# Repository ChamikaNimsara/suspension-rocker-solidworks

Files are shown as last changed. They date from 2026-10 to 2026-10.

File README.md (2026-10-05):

# Suspension Rocker Design, Kinematics and FEA in SolidWorks

**Author:** Chamika Nimsara | **Software:** SolidWorks 2023 | **Completed:** 5 October 2026

A conceptual front-corner pushrod suspension rocker project covering parametric modelling, a serviceable pivot assembly, travel verification, linear static FEA, mesh refinement and a mass-reduction iteration.

The optimized 6061-T6 rocker removes **41.23 g (6.72%)** using a through-hole while retaining the same pickup geometry. The matched-mesh bump comparison shows **1.66% higher peak nodal stress and 31.74% higher maximum displacement**. This is a documented mass/stiffness trade-off, rather than a claim that every performance metric improved.

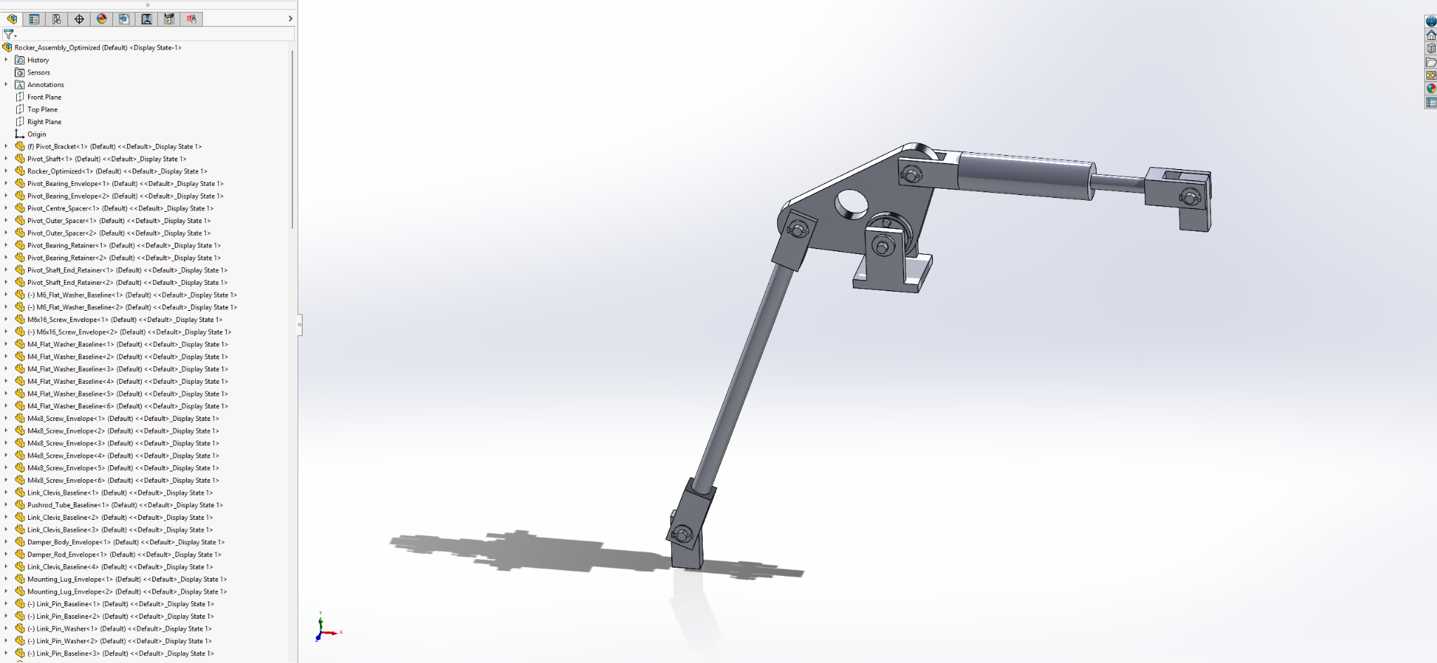
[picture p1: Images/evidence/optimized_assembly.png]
Optimized rocker assembly


## Results at a glance

| Quantity | Baseline | Optimized |
|---|---:|---:|
| Rocker body mass | 613.86 g | 572.63 g |
| Bump +30 mm / 6 kN, nodal stress, matched mesh | 82.43 MPa | 83.80 MPa |
| Bump +30 mm / 6 kN, resultant displacement, matched mesh | 0.04651 mm | 0.06127 mm |
| Bump fine-mesh nodal stress | 85.14 MPa | 83.87 MPa |
| Bump fine-mesh resultant displacement | 0.04655 mm | 0.06128 mm |
| Reverse 2 kN nodal stress | 31.60 MPa | 31.30 MPa |
| Reverse 2 kN resultant displacement | 0.01734 mm | 0.02256 mm |

Matched mesh = maximum/minimum mesh size **1.5/0.3 mm**; fine mesh = **1.2/0.24 mm**. Stress is a maximum nodal von Mises result, and displacement is maximum URES, not a measured relative pickup displacement.

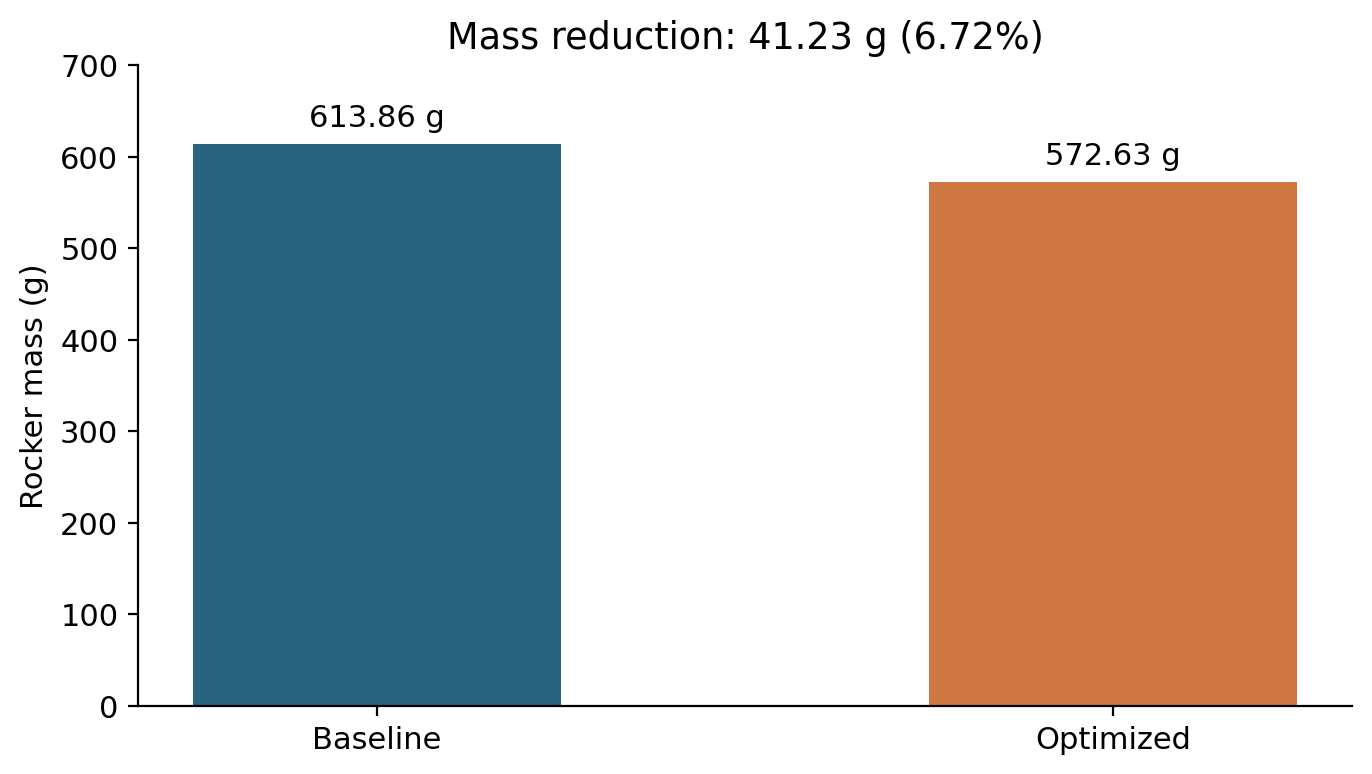
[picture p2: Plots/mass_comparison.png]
Mass comparison

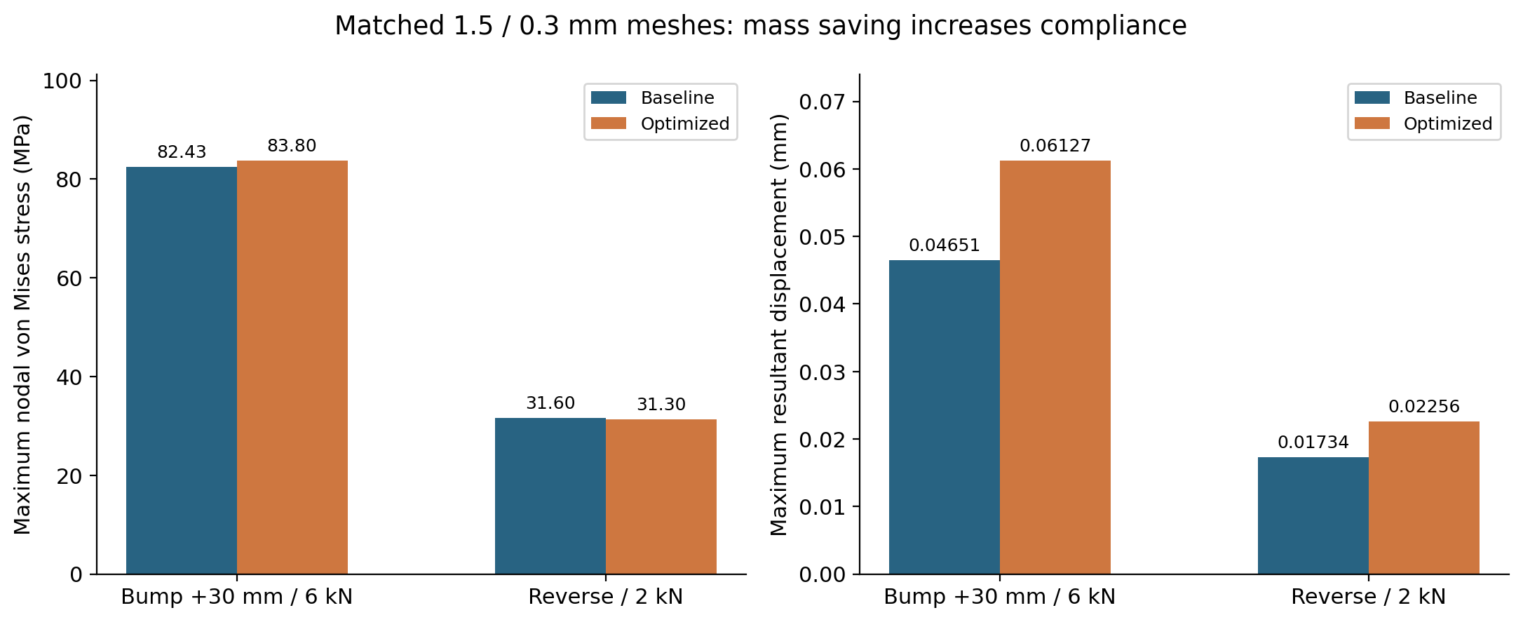
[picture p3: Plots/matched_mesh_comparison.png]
Matched-mesh structural comparison


## What was built and checked

- Baseline and optimized rocker bodies with unchanged A/O/B pickup locations.
- Pivot shaft, simplified bearings, spacers, retainers, fasteners and double-shear linkage joints.
- Pushrod and telescoping damper envelopes connected to a fixed mount and guided input.
- Nominal ride motion ratio approximately **0.80**, with travel-dependent variation measured from CAD.
- **30 mm bump / 30 mm droop** mechanism sweep; 21.19 mm compression and 27.33 mm extension from ride.
- Baseline ride, bump, droop and reverse bearing-load studies; optimized bump and reverse studies.
- Baseline and optimized bump mesh-refinement comparisons and reaction-force checks.
- Smooth optimized assembly motion reported by the author; no remaining interferences at the three checked positions after eight known thread-envelope overlaps were ignored.
- Optimized rocker and assembly drawings, including BOM and balloons, exported to PDF.

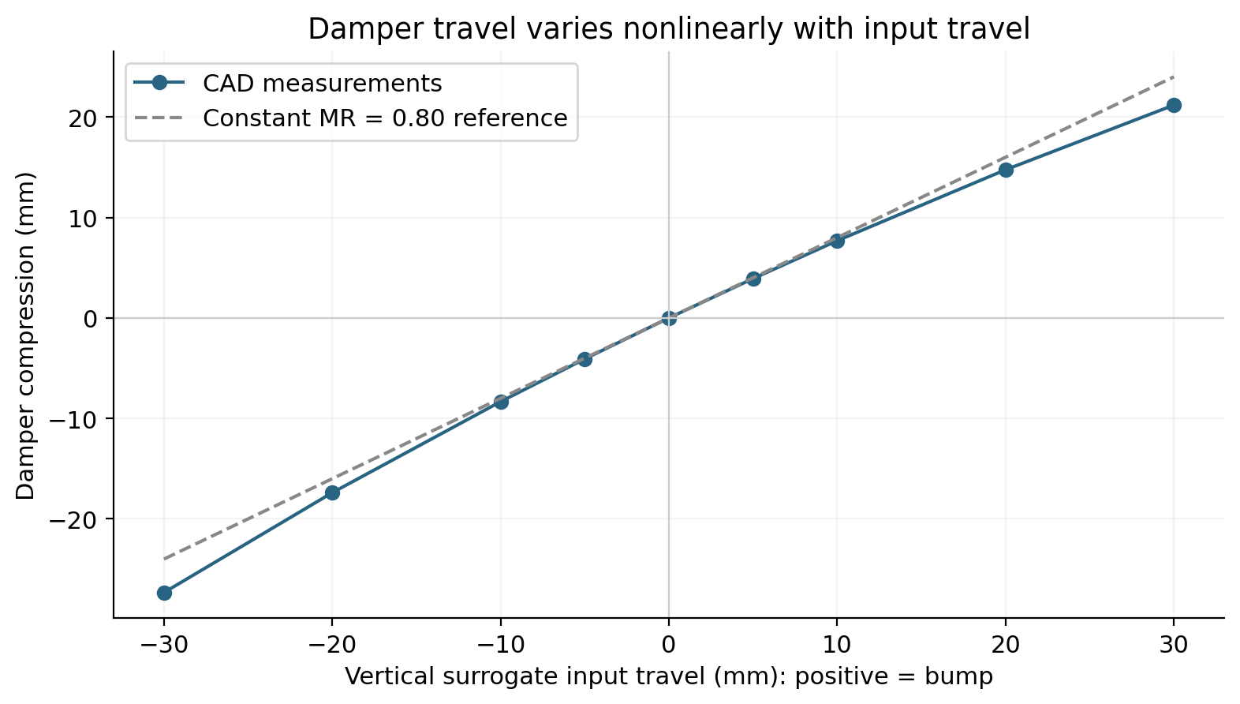
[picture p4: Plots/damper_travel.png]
Damper travel

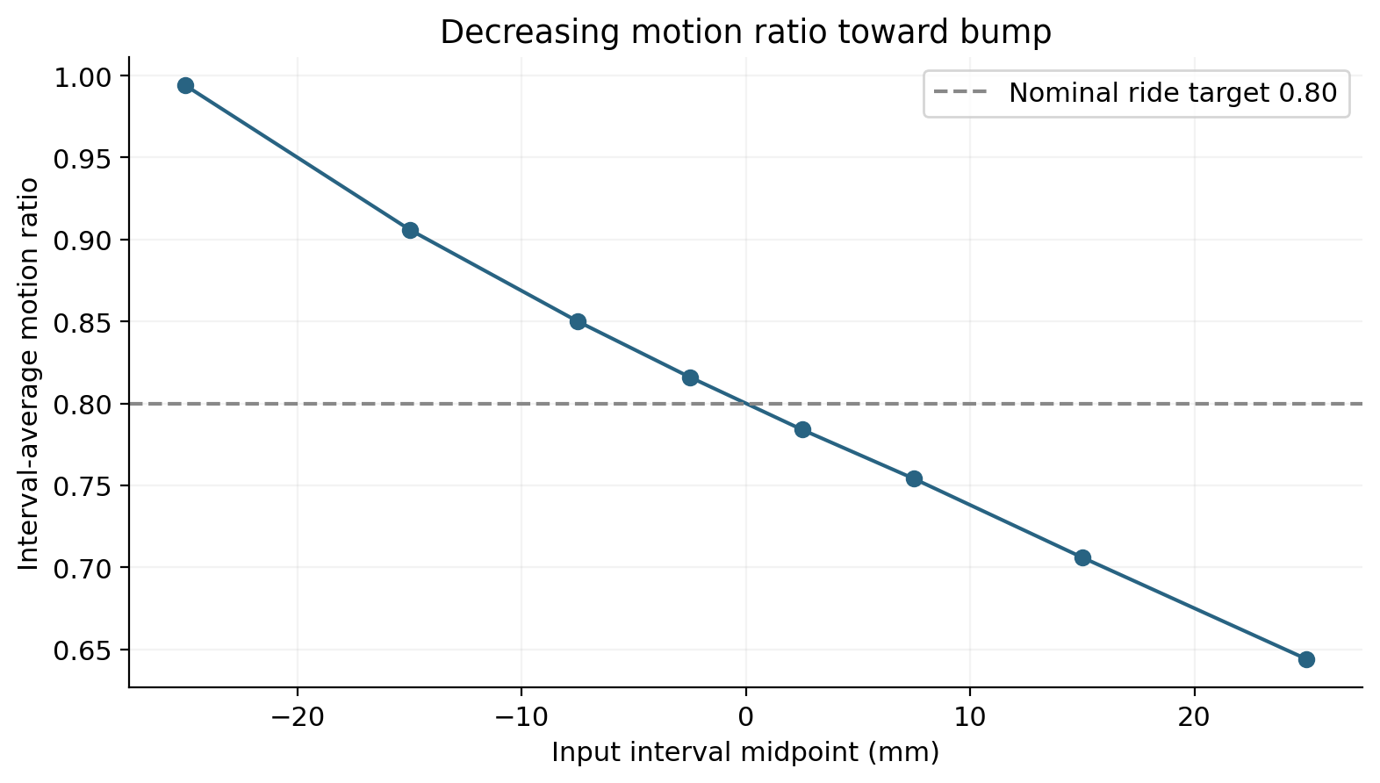
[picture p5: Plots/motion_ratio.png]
Motion ratio


## Read the engineering work

1. [Design basis and final geometry](docs/01_design_basis.md)
2. [Mechanism physics and kinematics](docs/02_kinematics.md)
3. [Loads, FEA setup and mesh checks](docs/03_structural_analysis.md)
4. [Optimization and interpretation](docs/04_optimization.md)
5. [Assembly verification and drawing status](docs/05_verification.md)
6. [Evidence gallery and data provenance](docs/06_evidence.md)
7. [Native files and publishing the repository](docs/07_repository_guide.md)
8. [Engineering Brief](docs/engineering_brief.md)

## Drawings

- [Optimized rocker part drawing](Drawings/Rocker_Optimized.pdf)
- [Optimized assembly drawing and BOM](Drawings/Rocker_Assembly_Optimized.pdf)

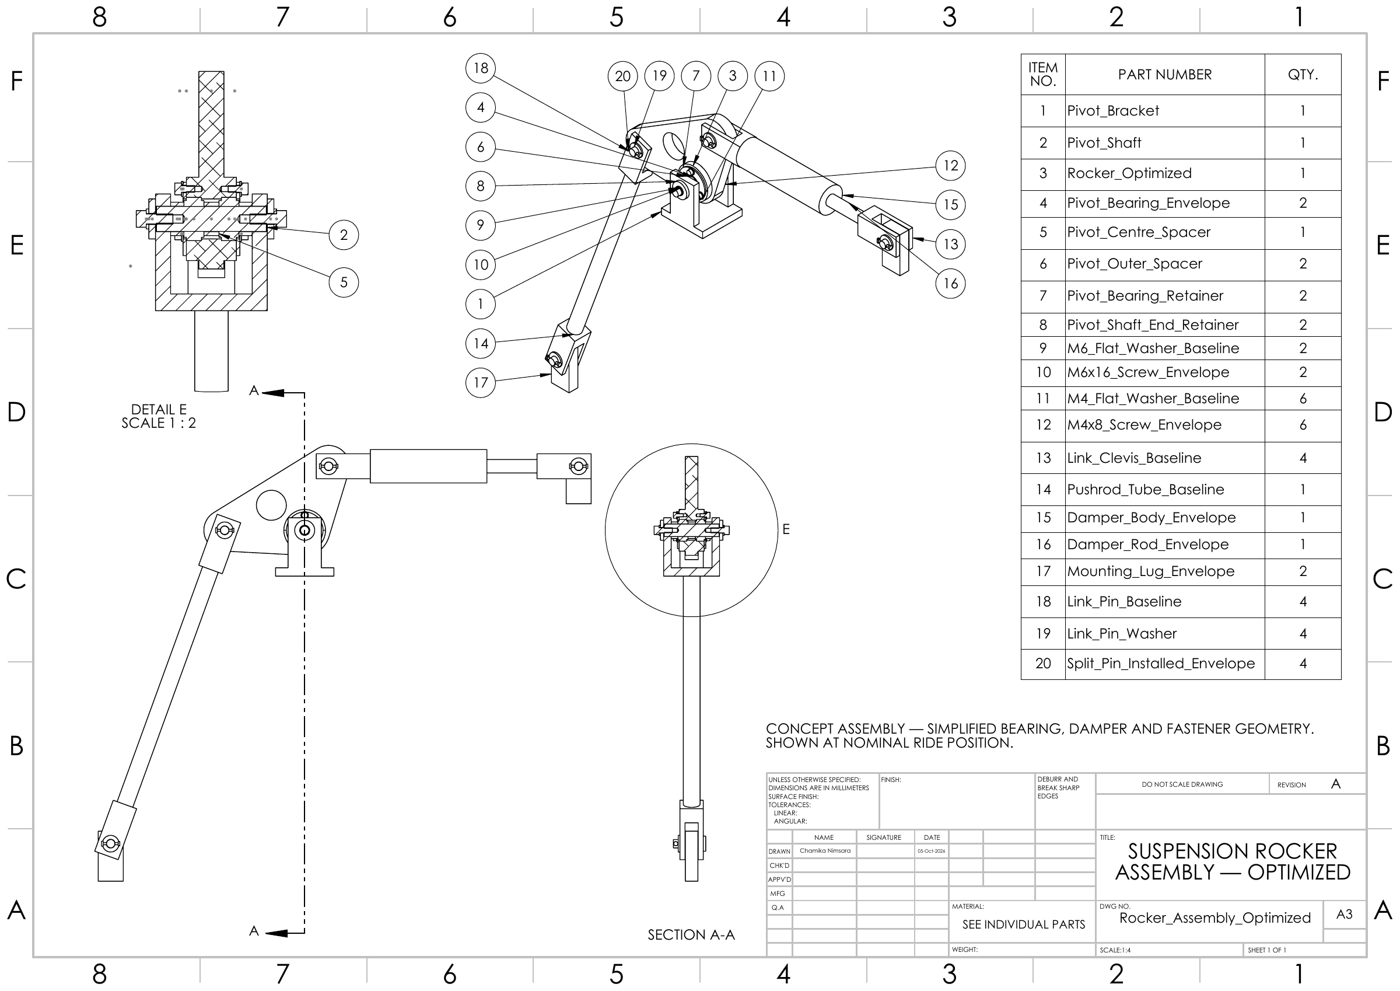
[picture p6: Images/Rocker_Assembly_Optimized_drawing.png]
Assembly drawing preview


## Repository contents

| Folder | Contents |
|---|---|
| `docs/` | Engineering explanations, final assumptions, methods and limitations |
| `Images/` | Drawing previews and selected original project screenshots |
| `Plots/` | Six reproducible figures, each in PNG and SVG |
| `Results/` | CSV records for kinematics, loads, mass, FEA, convergence, BOM and assembly checks; two interference-calculation spreadsheets and the screenshot evidence manifest |
| `Drawings/` | Two exported PDF drawings and their native `.SLDDRW` sources |
| `scripts/` | Python chart generation from the CSV records |
| `CAD/` | 22 native `.SLDPRT` models and two `.SLDASM` assemblies |
| `Simulation/` | Locally copied `.CWR` solver results, `.MFC`/`.SL4` artifacts and logs; `.CWR` and `.LOG` files are ignored by Git |
| `Animations/` | Baseline mechanism travel video, `Rocker_Travel_Baseline.avi` |

## Reproduce the figures

```bash
python -m pip install -r requirements.txt
python scripts/generate_charts.py
```

This recreates the plots from recorded values. It does **not** rerun SolidWorks or reconstruct a solver model. Native CAD, drawing sources, solver artifacts and the baseline animation are present in the local repository folders. The copied assemblies' and drawings' references and the studies' result paths have not been verified as part of this documentation review; see [the repository guide](docs/07_repository_guide.md). Git-ignored solver files are local artifacts and are not included by a normal Git commit.

## Interpretation and scope

The moving lower mount C is a **vertical surrogate input**, not a complete upright/wishbone model. Motion ratio is therefore damper compression per unit guided input travel. The full vehicle's wheel motion ratio would require its actual suspension geometry.

The mechanism has a decreasing motion ratio toward bump; it does not meet a constant 0.80 ±5% target across the whole sweep. Only selected static rocker load cases were analyzed. Bearing life, joint/shaft/bracket strength, chassis attachment, fatigue, impact loads and physical proof testing are outside the completed scope.

Drawings communicate nominal concept geometry; fits, general tolerances and a manufacturing release are not established. The eight ignored overlaps are known simplified screw/thread intersections, not a blanket permission to ignore interference. Grey reference markers in the assembly detail were intentionally retained by the author.

No open-source license has been selected. Choose an appropriate license before inviting reuse of the design or code.

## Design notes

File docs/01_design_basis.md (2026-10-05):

# Design basis and geometry

## Final scope

This portfolio project models one conceptual front-corner rocker mechanism. A rocker is a bell crank: it turns a force and displacement along the pushrod into a force and displacement along the spring/damper axis. The pivot transmits the remaining force to the chassis support.

The CAD project is complete within its stated concept scope. It is not a production suspension or a validated vehicle-specific design. The final material is **6061-T6**, not the 7075-T6 proposed in the early brief.

## Final inputs and assumptions

| Parameter | Adopted value | Interpretation |
|---|---:|---|
| Reference front stiffness | 67,500 N/m | Treated as a wheel-rate reference for the local spring calculation |
| Nominal ride motion ratio | 0.80 | Compression / guided vertical input travel |
| Derived local spring rate | 105.47 N/mm | 67.5 / 0.8²; nominal equivalent, not a purchased spring |
| Mechanism input range | -30 to +30 mm | Negative droop, positive bump |
| Static proof sensitivity input | 6,000 N | Assumed vertical input load, not a measured race load |
| Reverse input | -2,000 N | Assumed load reversal at ride |
| Material E / Poisson ratio | 69,000 MPa / 0.33 | SolidWorks analysis material settings |
| Density | 2,700 kg/m³ | Analysis/CAD material setting |
| Yield / tensile strength | 275 / 310 MPa | Library values, not a billet certificate |

Vehicle mass and track inspired the concept, but do not independently derive the applied 6 kN load. Real sizing would require actual hard points, aero loads, tyre forces, load histories and an operating duty cycle.

## Coordinate convention

O is the rocker pivot, x points right in the layout, y points up and z follows the shaft. All coordinates below are in millimetres and refer to the planar ride layout.

| Point | x | y | Function |
|---|---:|---:|---|
| O | 0 | 0 | Fixed pivot |
| A | -96 | 0 | Pushrod pickup |
| B | 28.73604009 | 76.8 | Damper pickup |
| C | approximately -232.81 | approximately -375.88 | Guided lower pushrod mount |
| D | approximately 328.74 | 76.8 | Fixed damper mount |

OA = 96 mm, OB = 82 mm; pushrod pin-centre length AC = 400 mm and nominal damper pin-centre length BD ≈300 mm. Rounded C/D coordinates are sufficient for interpretation; the saved CAD constraints govern the model.

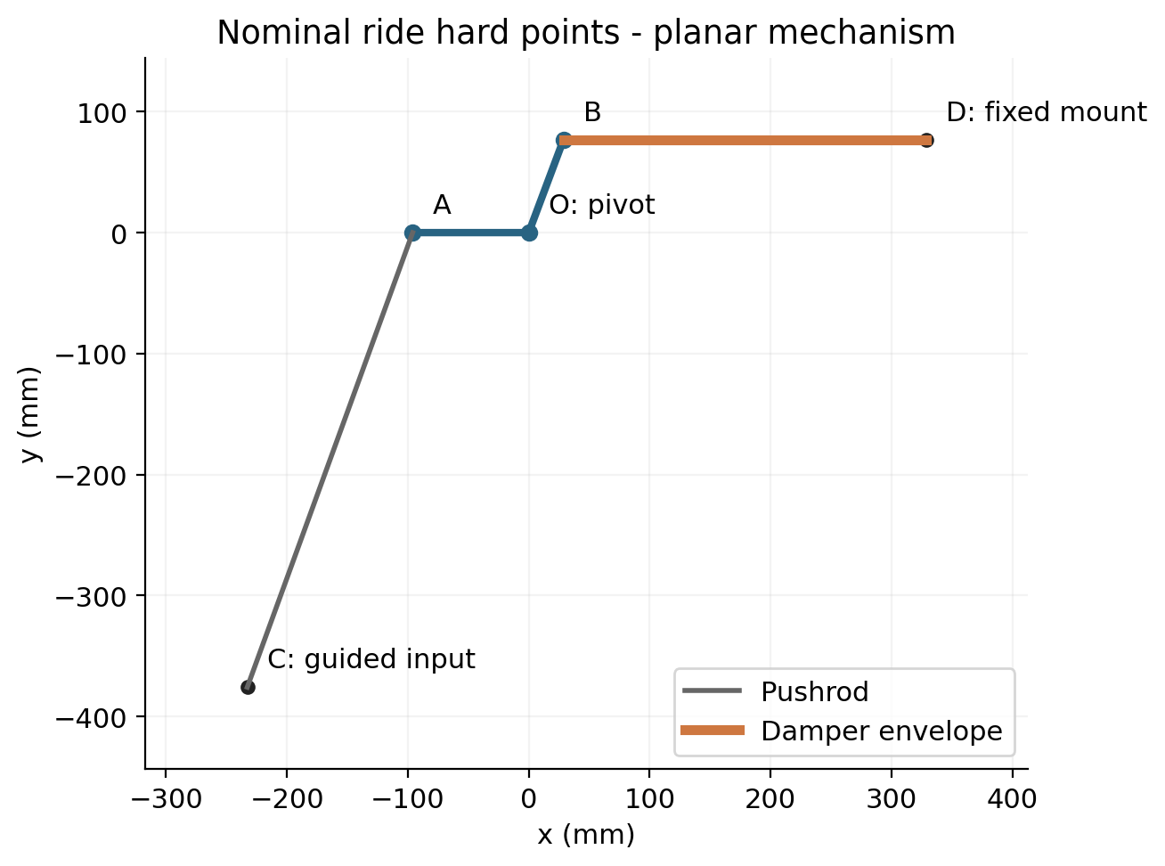
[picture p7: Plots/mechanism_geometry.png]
Ride geometry


## Rocker body features

| Feature | Final nominal geometry |
|---|---|
| Plate | 15 mm, mid-plane extrusion |
| Pivot hub | Ø50 mm, 30 mm total axial thickness |
| Pivot through opening | Ø24 mm |
| Bearing seat | Ø26 mm, 9 mm depth on each end |
| Linkage holes | Ø10 mm through |
| Outer profile | Tangent lines linking R25 pickup arcs and R30 pivot profile |
| Retainer pattern | 3 × M4 ×0.7 each side, Ø36 mm PCD, 120° spacing |
| Thread / tap drill depth | 6 / 9 mm each side; Ø3.3 mm drill |
| Optimized window | Ø36 mm through, centre (-40,+30) relative to O |
| Window-to-hub radial clearance | 7 mm nominal: 50 - 25 - 18 |

No fillets were added to the final nominal model. Hole position, root geometry and window placement influence the load path; nominal clearances do not establish manufacturing tolerances or fatigue durability.

## Changes from the early concept

| Early proposal | Completed project |
|---|---|
| 7075-T6 body | 6061-T6 body |
| 50 mm bump / 30 mm droop | Demonstrated ±30 mm guided-input travel |
| Preliminary 95 mm pushrod radius | Final OA = 96 mm |
| Hypothetical 50 N/mm spring example | 105.47 N/mm local spring-rate calculation |
| Constant MR within ±5% as an initial aim | Measured decreasing ratio; departure explicitly documented |
| 0.20-0.30 kg preliminary mass ambition | Baseline 0.61386 kg; optimized 0.57263 kg |
| Proposed blend radii, certified material and release fits | Nominal concept CAD and drawings; those release items remain open |

The early concept brief is not used as final numerical evidence. This document describes what was actually modelled and measured.

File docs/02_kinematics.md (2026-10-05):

# Mechanism physics and kinematics

## Displacement and force transformation

For a small rotation dθ, the velocity of a rocker pickup is perpendicular to the arm from O. Its projection along the connected link axis determines the axial motion transferred through that link. The rigid pushrod retains its length, so the velocities of A and C have equal projections along AC; damper compression depends on the relative axial velocity of B and D. The effective arm is therefore

$$e=|\mathbf r\times\hat{\mathbf u}|.$$

The arm's physical radius alone is not the motion ratio: pushrod angle and damper line of action also matter. At ride, A has a 96 mm horizontal arm, while a horizontal damper force at B has a 76.8 mm moment arm. Their ratio is 0.80 for the guided-input layout near ride.

Define positive q as upward guided input C and positive s as damper compression:

$$MR=\frac{ds}{dq}.$$

Under lossless, quasi-static virtual work,

$$F_q\,dq=F_d\,ds,\qquad F_d=F_q/MR.$$

A damper that moves less than the input must carry more force. At ride MR ≈0.80, a 6 kN input corresponds to approximately 7.5 kN at the damper. A bearing pressure is applied at the rocker pickup to represent this force transfer in the structural model.

## Spring-rate relationship

For an approximately constant local MR, the equivalent input stiffness is

$$k_q\approx k_sMR^2.$$

One factor of MR comes from displacement transformation and the other from force transformation. A 67.5 N/mm input stiffness at MR=0.80 requires approximately 105.47 N/mm spring stiffness. This is a local calculation, not a specification of a catalogue spring.

When MR varies and the spring carries force, the tangent stiffness includes a geometric term:

$$\frac{dF_q}{dq}=k_sMR^2+F_s\frac{dMR}{dq}.$$

Preload and ride force matter to that term. It is not valid to claim a constant wheel rate across travel solely from the ride ratio.

## Recorded sweep

| Input q (mm) | Mate distance (mm) | Damper length BD (mm) | Compression s (mm) |
|---:|---:|---:|---:|
| -30 | 405.88 | 327.34 | -27.33 |
| -20 | 395.88 | 317.40 | -17.39 |
| -10 | 385.88 | 308.34 | -8.33 |
| -5 | 380.88 | 304.09 | -4.08 |
| 0 | 375.88 | 300.01 | 0.00 |
| +5 | 370.88 | 296.09 | 3.92 |
| +10 | 365.88 | 292.32 | 7.69 |
| +20 | 355.88 | 285.26 | 14.75 |
| +30 | 345.88 | 278.82 | 21.19 |

The independently displayed lengths and compression records are rounded to 0.01 mm; small differences in their subtraction should not be treated as new measurements.

Travel curve

The central ±5 mm estimate is (3.92 - (-4.08))/10 = **0.800**. Finite-interval ratios decrease toward bump: 0 to +10 mm gives 0.769, +10 to +20 gives 0.706, and +20 to +30 gives 0.644. Toward droop, interval values are 0.833, 0.906 and 0.994. The smaller ±5 mm intervals are retained in the CSV and plot.

Interval-average motion ratio

The plot uses Δs/Δq at interval midpoints; it is not an exact analytic derivative. Measured travel is **21.19 mm compression**, **27.33 mm extension** and **48.52 mm total excursion**. The envelope model does not establish a real damper's available stroke or bump-stop margin.

## Important boundary of the result

C is constrained to a vertical guide. There is no upright, wishbone geometry, steering sweep or tyre contact point in this assembly. Call this ratio damper-to-guided-input MR; mapping it to actual wheel motion requires a full suspension model. The decreasing ratio also departs from the initial constant-ratio ±5% ambition and is retained as a measured result, not hidden as an acceptance pass.

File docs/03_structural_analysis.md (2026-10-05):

# Loads, structural analysis and mesh checks

## What the analysis represents

Linear elastic static studies were performed on the rocker solid in SolidWorks Simulation. Force inputs are selected concept load cases, not measured wheel loads or dynamic test results. The bearing-load models are the final reported structural studies; preliminary uniform cylindrical traction studies are not mixed into the headline comparison.

A real joint transfers force through contact pressure around a pin. A point force would concentrate the load unrealistically. Distributed bearing loads provide a more representative load direction, although they still do not resolve actual pin flexibility, clearance or nonlinear contact.

## Material and fixtures

- 6061-T6, isotropic linear elasticity: E = 69,000 MPa, ν =0.33, density =2,700 kg/m³.
- Material-library yield/tensile values 275/310 MPa, without certified billet data.
- Fixed Hinge on the two Ø26 mm bearing seats: radial and axial displacement constrained, circumferential freedom retained.
- A small angular-reference fixture at a split-line vertex, approximately (13,0,15) mm, removes the otherwise free rigid rotation about the pivot.
- The angular reference is a numerical stabilizer. Its reaction is checked; it is not a physical chassis attachment.
- Soft springs, inertia relief and large displacement were off; free-body reaction extraction was on.

## Force magnitudes and directions

| Case | Vertical input | Pushrod magnitude | Damper magnitude | Pushrod axis angle, body-fixed | Damper axis angle, body-fixed |
|---|---:|---:|---:|---:|---:|
| Ride proof | +6,000 N | 6,385.07 N | 7,500 N | 70° | 0° |
| +30 mm bump proof | +6,000 N | 6,412.26 N | 9,807.04 N | 86.55° | 19.66° |
| -30 mm droop proof | +6,000 N | 6,420.13 N | 5,728.17 N | 49.65° | -20.42° |
| Ride reverse | -2,000 N | 2,128.36 N | 2,500 N | 70° | 0° |

Angles are link-axis orientations measured from the rocker's body-fixed x axis in the rocker-only FEA model. This frame coincides with the assembly's global frame at ride, but rotates with the rocker during bump and droop. If θ is the rocker rotation from ride, the assembly-global link angle equals the listed body-fixed angle plus θ. For example, at +30 mm bump θ is approximately -17.21°, giving global pushrod/damper angles of approximately 69.34°/2.45°. The vertical input in the table is defined along the assembly's global guided-input axis, not the body-fixed y axis. In proof cases the pushrod force follows the axis from C toward A and the damper force opposes the axis from B toward D; reverse changes both directions. Exact CAD coordinates govern the case. Loads were recalculated at the displaced geometry, rather than applying the ride force unchanged throughout travel.

Moment equilibrium about O requires $F_pe_p=F_de_d$. Ride proof torque magnitude is about 576 N·m. Bump proof torque magnitude is about 614.46 N·m; droop proof approximately 469.71 N·m. Reverse ride torque magnitude is about 192 N·m.

## Reported maximum results

| Design / case | Mesh max/min (mm) | Nodal von Mises (MPa) | URES (mm) | Equivalent strain |
|---|---|---:|---:|---:|
| Baseline ride proof | 1.5/0.3 | 71.70 | 0.04787 | 0.0007846 |
| Baseline reverse | 1.5/0.3 | 31.60 | 0.01734 | 0.0003425 |
| Baseline bump proof | 1.5/0.3 | 82.43 | 0.04651 | 0.0009858 |
| Baseline bump proof, fine | 1.2/0.24 | 85.14 | 0.04655 | 0.001002 |
| Baseline droop proof | 1.5/0.3 | 65.60 | 0.04061 | 0.0007201 |
| Optimized bump proof | 1.5/0.3 | 83.80 | 0.06127 | 0.001001 |
| Optimized bump proof, fine | 1.2/0.24 | 83.87 | 0.06128 | 0.001004 |
| Optimized reverse | 1.5/0.3 | 31.30 | 0.02256 | 0.0003441 |

URES is maximum absolute resultant displacement. It does not establish relative A-to-B deflection, bearing-seat ovalization or complete suspension compliance. Colour plots use automatic contour scales; compare numeric values, not colour intensity. Displayed deformation is magnified by the plot scale, not actual movement.

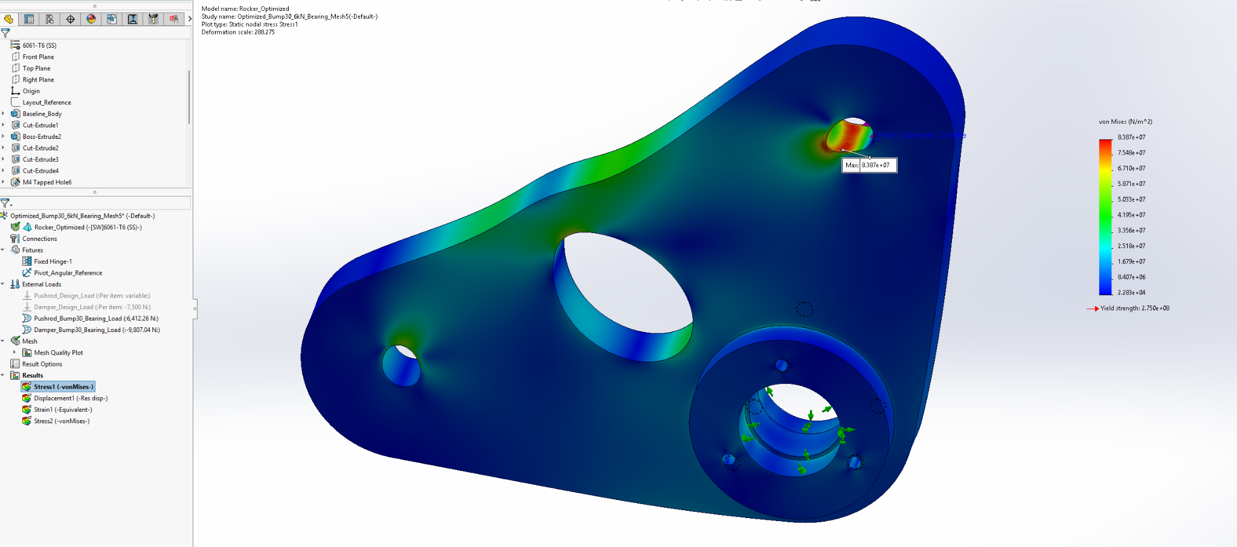
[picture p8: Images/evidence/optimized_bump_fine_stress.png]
Optimized bump fine stress

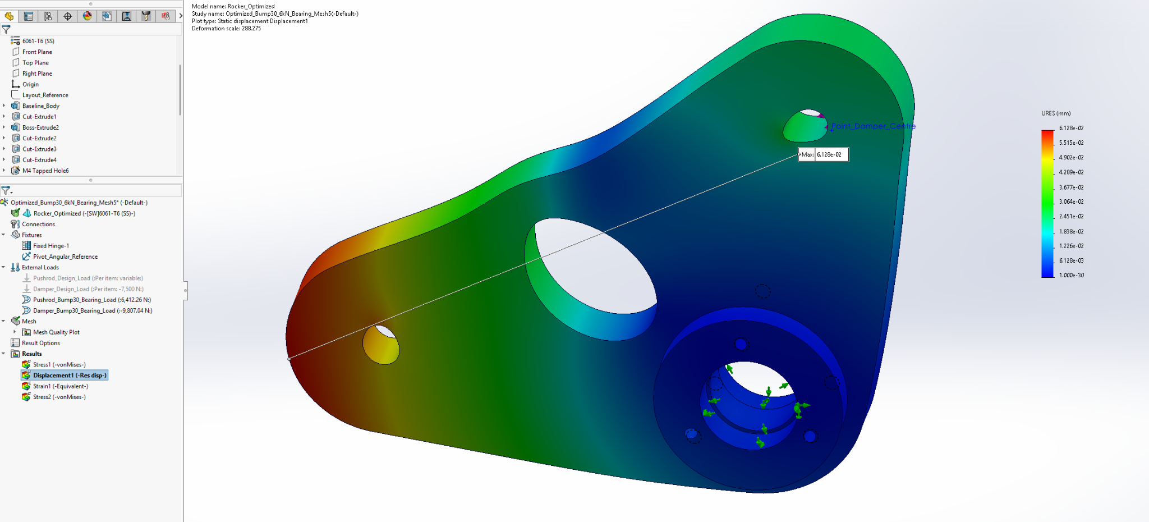
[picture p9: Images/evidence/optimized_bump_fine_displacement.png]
Optimized bump fine displacement


## Mesh and convergence

High-quality solid blended curvature-based meshing was used, with Jacobian checks at 16 points, 16 elements around a circle and growth ratio 1.4. The final refinement interval is summarized below.

| Design | Coarse nodes / elements | Fine nodes / elements | Stress change | URES change | Strain change |
|---|---|---|---:|---:|---:|
| Baseline bump | 784,424 / 554,512 | 1,342,608 / 956,878 | +3.29% | +0.086% | +1.64% |
| Optimized bump | 748,824 / 527,910 | 1,267,794 / 901,045 | +0.084% | +0.016% | +0.300% |

The adopted project check was less than 5% change in stress and 2% in displacement over the final refinement. Both pass that numerical check. Baseline fine maximum aspect ratio was 5.1419, optimized fine 5.2676, with no reported distorted elements or aspect ratios above 10. This documents stability across the final interval; it does not prove exact stress convergence, eliminate singularities or validate the fixture model.

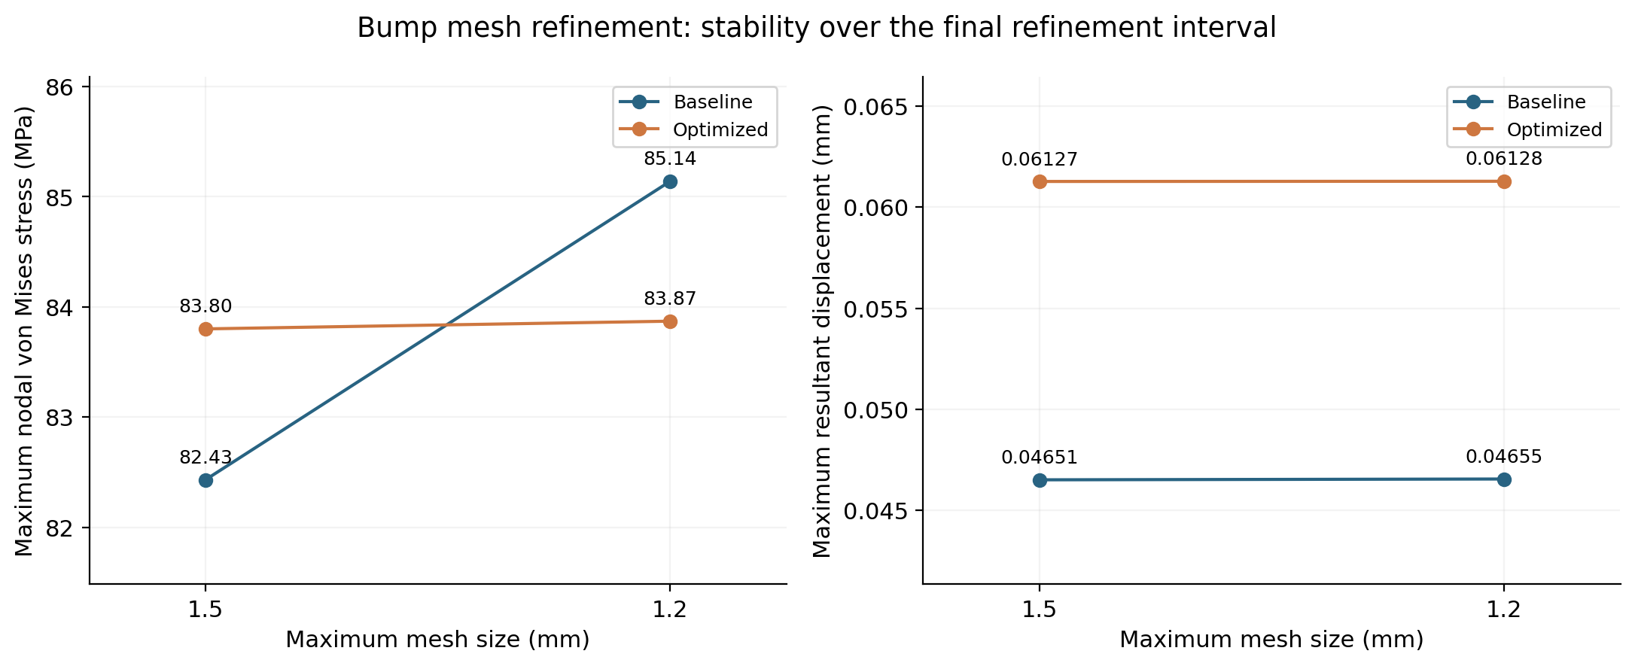
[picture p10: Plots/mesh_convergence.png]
Mesh refinement results


## Equilibrium and stabilization checks

For the optimized fine bump case, the expected net pivot reaction in the same body-fixed FEA frame is approximately (8849.47,-3101.18,0) N. The extracted result in that frame was (8849.6,-3101.3,+0.0698) N. These components are not expressed in the assembly's global frame at bump. The angular-reference resultant was approximately **0.411 N**, with pivot-axis moment approximately **0.00276 N·m**, small compared with the applied 614.46 N·m torque magnitude. This supports that the stabilizer was not carrying a material fraction of the intended load.

The optimized reverse angular-reference resultant was approximately 0.310 N with pivot-axis moment -0.00281 N·m. The baseline fine bump reference resultant was approximately 0.265 N with pivot-axis moment 0.000501 N·m. Reaction agreement is a model consistency check, not proof of physical correctness.

## Limits

No optimized ride/droop study or reverse mesh-refinement sequence is claimed. Bump was the largest-stress baseline case tested and was selected for the optimized refinement. All assembly hardware remains outside the rocker-only stress assessment. No fatigue spectrum, modal analysis, buckling study, impact simulation, nonlinear contact study or physical testing is included. A yield-strength/peak-stress quotient alone would not establish a safe vehicle design.

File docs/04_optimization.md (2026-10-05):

# Mass reduction and interpretation

The optimization was a single geometric iteration: a Ø36 mm through-window was added at x=-40 mm, y=+30 mm relative to O. Pickup locations, hub and plate thickness were retained so the assemblies use the same mechanism geometry.

Removing material reduces mass, but also reduces the area and bending stiffness through which loads flow. The correct comparison therefore includes mass, stress and displacement under matching boundary conditions.

## Quantified trade-off

| Metric | Baseline | Optimized | Change |
|---|---:|---:|---:|
| Mass | 613.86 g | 572.63 g | -41.23 g / -6.72% |
| Volume | 227,354.57 mm³ | 212,086.43 mm³ | -15,268.14 mm³ |
| Bump stress, 1.5/0.3 mm mesh | 82.43 MPa | 83.80 MPa | +1.66% |
| Bump URES, 1.5/0.3 mm mesh | 0.04651 mm | 0.06127 mm | +31.74% |
| Reverse stress, 1.5/0.3 mm mesh | 31.60 MPa | 31.30 MPa | -0.95% |
| Reverse URES, 1.5/0.3 mm mesh | 0.01734 mm | 0.02256 mm | +30.10% |

Mass
Matched mesh comparison

At the fine meshes, bump stress is 85.14 MPa baseline and 83.87 MPa optimized, while URES is 0.04655 versus 0.06128 mm. The slight stress decrease in that comparison should not be presented as a robust improvement in strength: coarse-to-fine baseline variation is larger than the between-design difference, and peak nodal stress depends on discretization and local load distribution.

The most defensible conclusion is **6.72% lower rocker body mass, similar computed bump stress, and roughly 32% greater maximum bump displacement** under these idealized cases. Whether that extra compliance is acceptable needs a relative pickup-deflection requirement and a full suspension compliance budget.

## Engineering judgment

The iteration demonstrates the workflow from baseline geometry to a tested mass change. It is not topology optimization or proof that this is the best possible geometry. A second iteration could investigate window shape, blended transitions, fillets and hub proportions, but would need to preserve machinability and reconsider fatigue/contact behaviour. Such changes were not performed in this project.

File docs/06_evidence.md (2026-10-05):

# Evidence gallery and provenance

The numeric CSV records were transcribed from the completed project conversation and supplied SolidWorks screenshots. They are rounded reported results, not raw solver exports. The plot-generation script performs calculations and visualization only.

Selected original screenshots below are retained without alteration; their source names and SHA-256 hashes are in [the evidence manifest](../Results/evidence_manifest.json). Fine-mesh stress and displacement values were visually checked against the included plots during packaging. Other numerical records derive from the recorded project results.

## Optimized assembly at nominal ride position

Optimized assembly at nominal ride position

## Optimized rocker geometry and feature tree

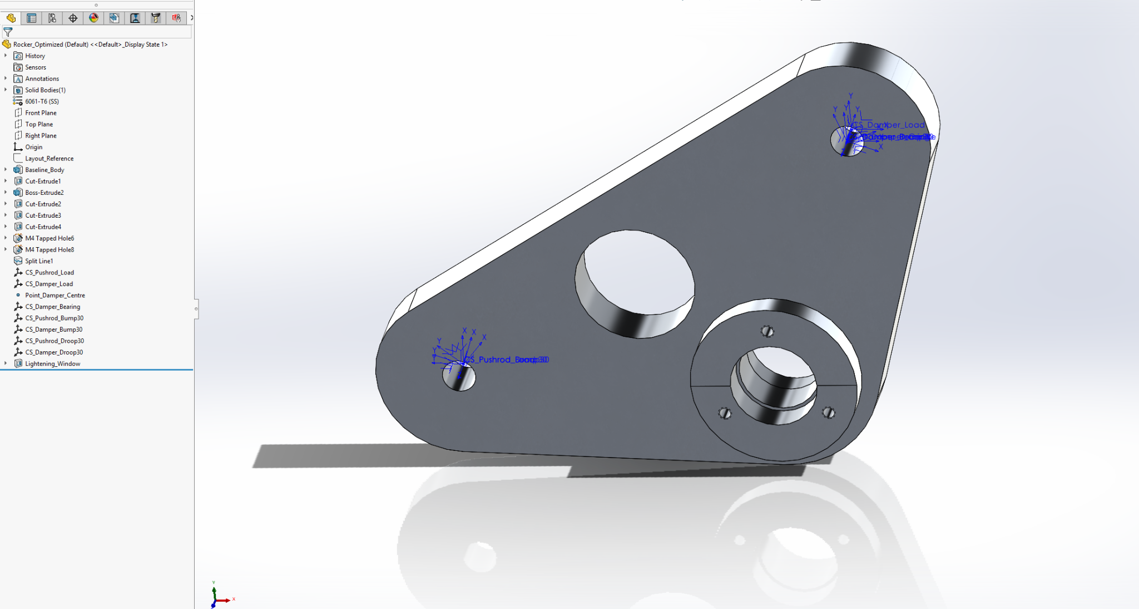
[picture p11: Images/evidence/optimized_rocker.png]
Optimized rocker geometry and feature tree


## Baseline bump, fine mesh: nodal von Mises 85.14 MPa

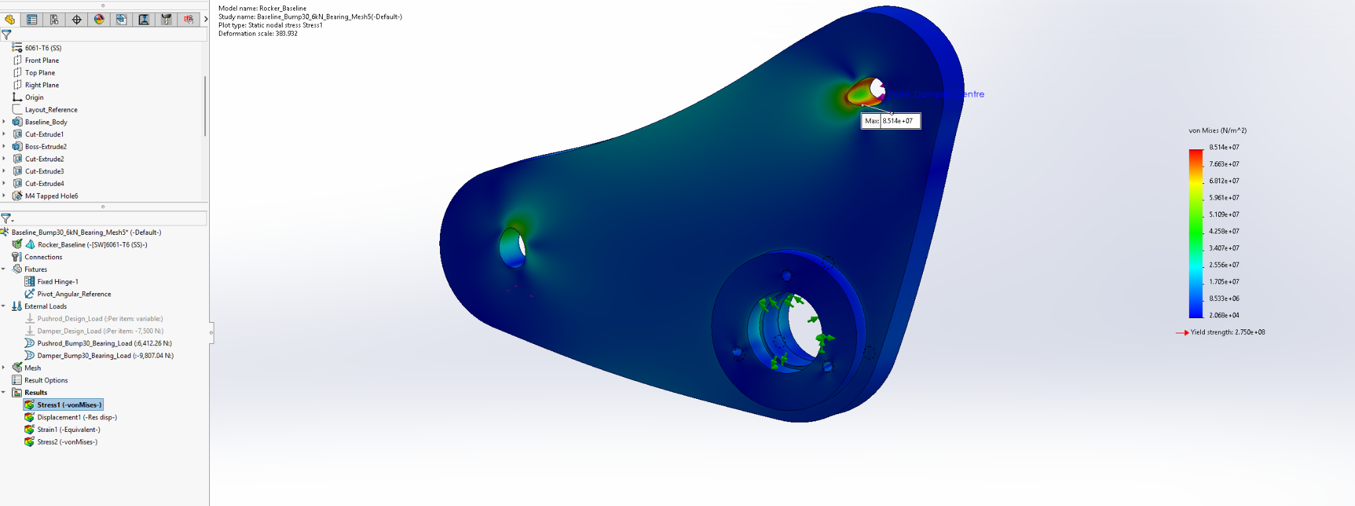
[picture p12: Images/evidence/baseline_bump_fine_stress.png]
Baseline bump, fine mesh: nodal von Mises 85.14 MPa


## Baseline bump, fine mesh: URES 0.04655 mm

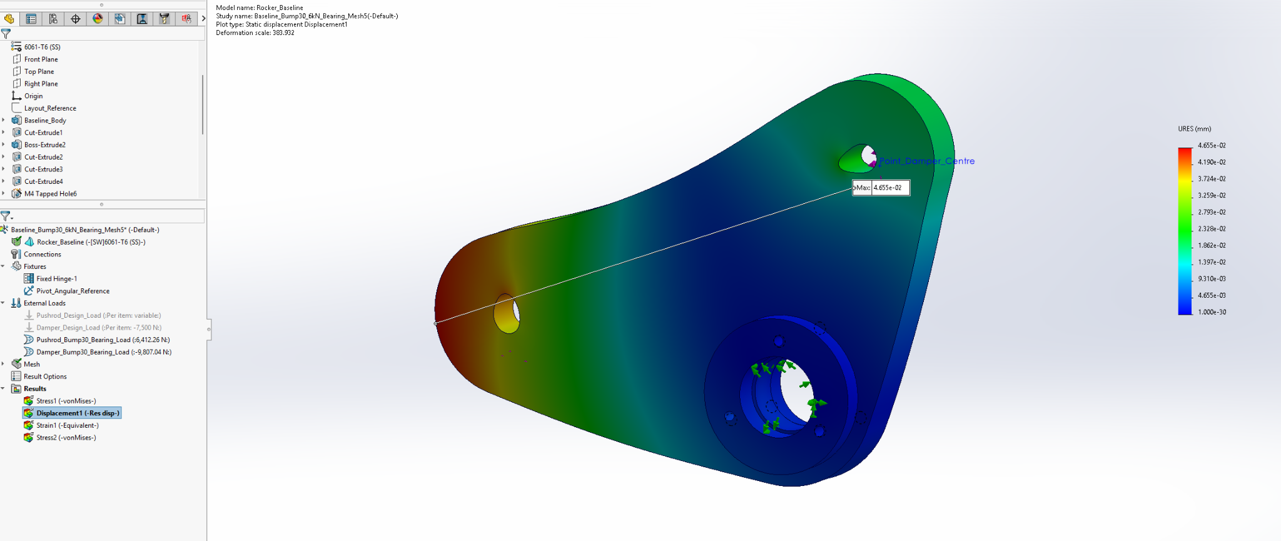
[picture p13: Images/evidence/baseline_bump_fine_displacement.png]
Baseline bump, fine mesh: URES 0.04655 mm


## Baseline bump, fine mesh: ESTRN 0.001002

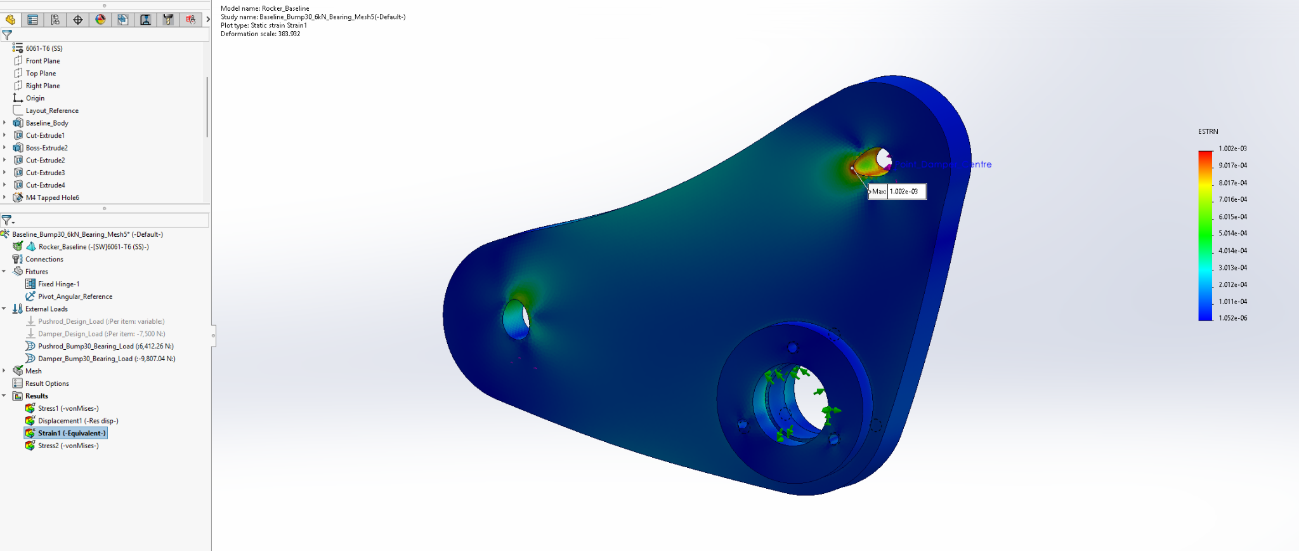
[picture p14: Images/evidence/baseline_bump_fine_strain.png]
Baseline bump, fine mesh: ESTRN 0.001002


## Optimized bump, coarse mesh: nodal von Mises 83.80 MPa

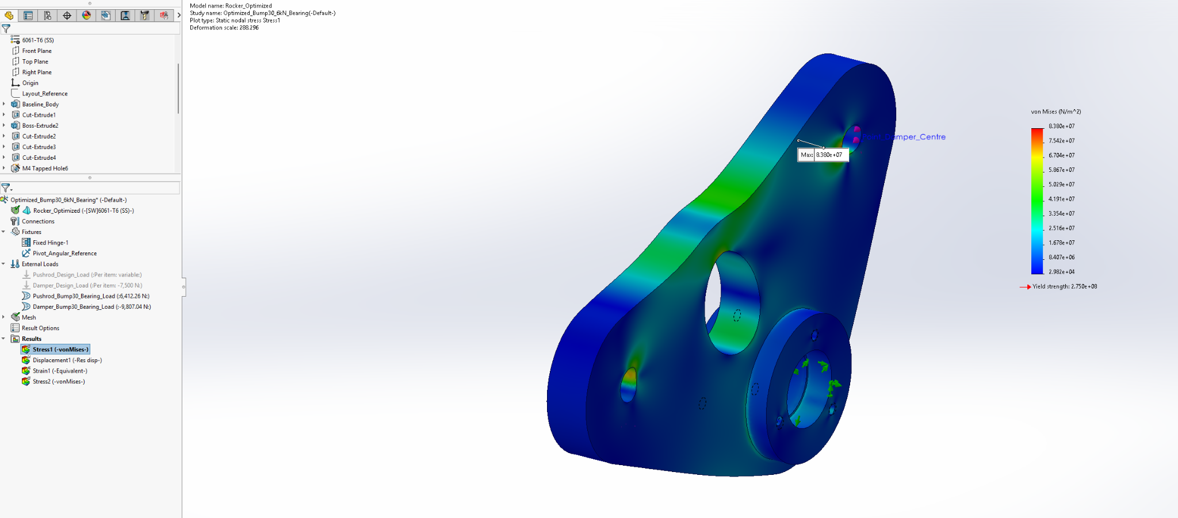
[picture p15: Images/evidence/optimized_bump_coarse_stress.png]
Optimized bump, coarse mesh: nodal von Mises 83.80 MPa


## Optimized bump, fine mesh: nodal von Mises 83.87 MPa

Optimized bump, fine mesh: nodal von Mises 83.87 MPa

## Optimized bump, fine mesh: URES 0.06128 mm

Optimized bump, fine mesh: URES 0.06128 mm

## Optimized bump, fine mesh: ESTRN 0.001004

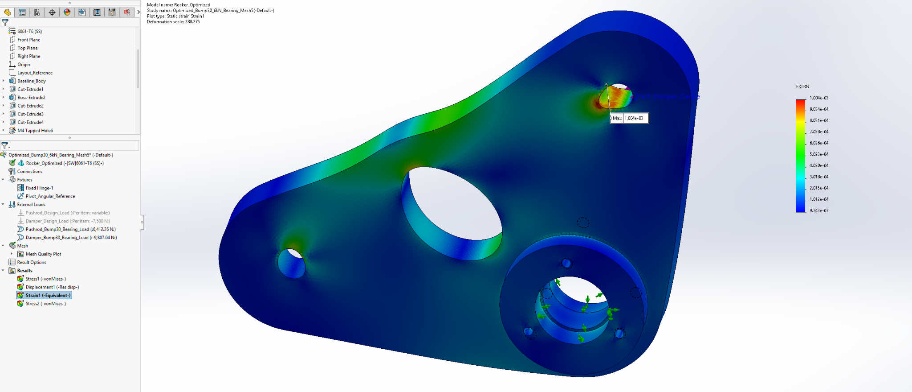
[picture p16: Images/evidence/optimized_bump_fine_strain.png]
Optimized bump, fine mesh: ESTRN 0.001004


## Optimized reverse: nodal von Mises 31.30 MPa

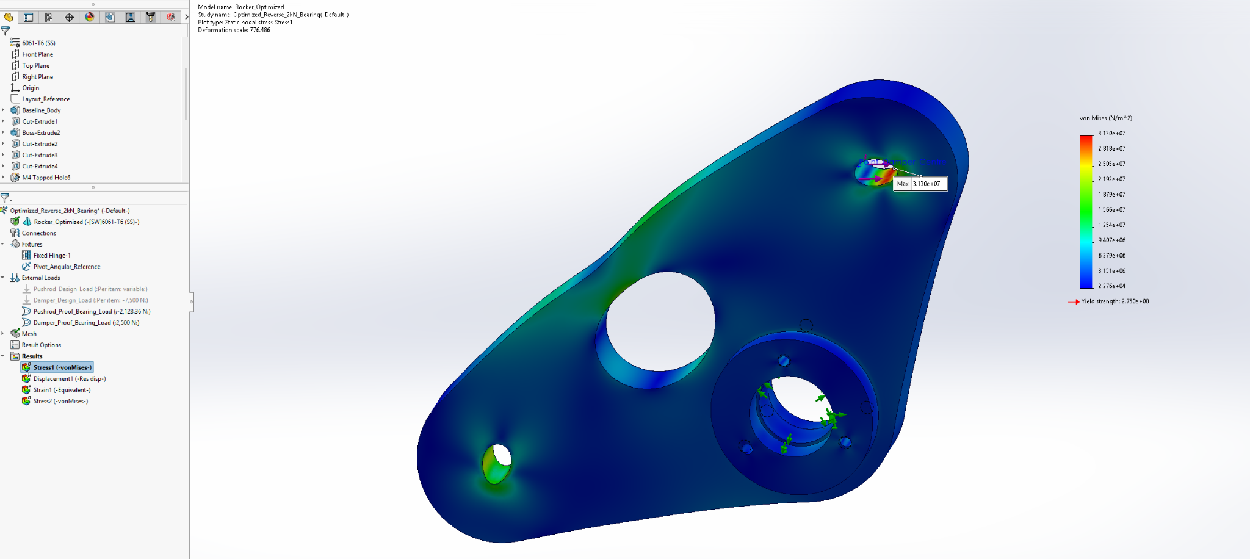
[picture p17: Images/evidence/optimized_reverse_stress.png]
Optimized reverse: nodal von Mises 31.30 MPa


## Optimized reverse: URES 0.02256 mm

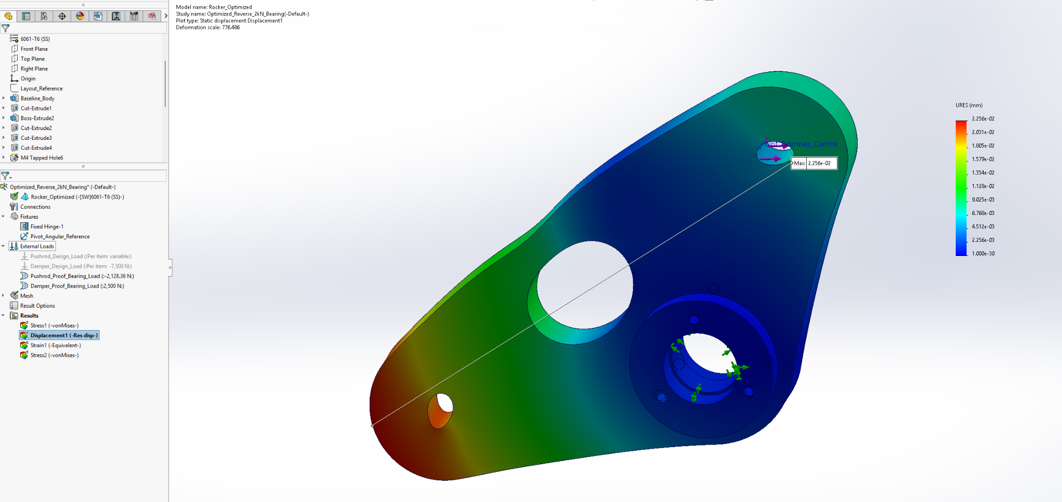
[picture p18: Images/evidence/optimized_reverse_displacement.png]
Optimized reverse: URES 0.02256 mm


## Optimized reverse: ESTRN 0.0003441

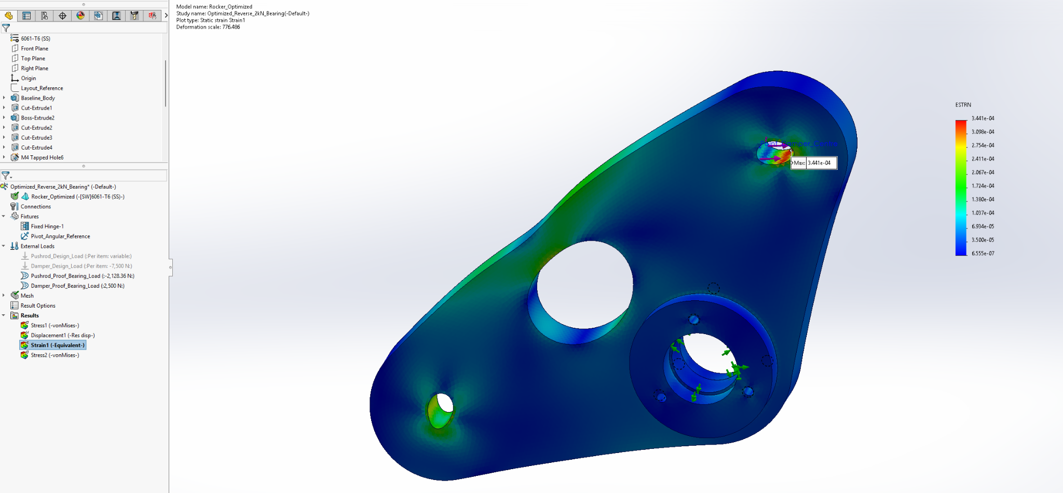
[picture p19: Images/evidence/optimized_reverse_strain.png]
Optimized reverse: ESTRN 0.0003441


## Reading the screenshots

Colour legends for stress are in N/m² (Pa): divide by 10⁶ for MPa. URES is in mm and ESTRN is dimensionless. Contour scales and displayed deformation magnifications vary between plots. Screenshot asterisks may indicate an unsaved document state at capture time; the final rebuild/save was performed later. Screenshots are evidence snapshots, not executable analysis files.

## Data index

- `kinematics.csv`: guided input and damper travel.
- `motion_ratio_intervals.csv`: derived Δs/Δq across every recorded interval.
- `mass.csv`: rocker-only CAD mass/volume.
- `load_cases.csv`: conceptual force inputs and local axis directions.
- `fea_results.csv`: maximum plot values and mesh statistics.
- `mesh_convergence.csv`: derived final refinement changes.
- `bom.csv`: assembly drawing items and quantities.
- `assembly_checks.csv`: author-confirmed optimized interference checks.

There are no simulated time histories or physical test measurements in this dataset.

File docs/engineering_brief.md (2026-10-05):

# Suspension Rocker Engineering Brief

**Author:** Chamika Nimsara  
**Software:** SolidWorks 2023  
**Completed:** 5 October 2026

> **6.72% lower rocker mass**, with similar computed bump stress and approximately **32% higher maximum displacement**. The iteration demonstrates a measured mass/stiffness trade-off.

## Objective and design

Develop a conceptual front-corner pushrod suspension rocker that redirects input movement into damper compression, then evaluate its kinematics, assembly packaging and structural response. The 6061-T6 body uses 96 mm and 82 mm pickup radii, a 15 mm plate and a 30 mm pivot hub. A Ø36 mm through-window provides the mass-reduction iteration while preserving the pickup geometry.

## Engineering method

Parametric modelling and assembly mates established the mechanism, pivot stack and linkage joints. A vertical guided input was swept through ±30 mm to measure damper travel. Linear elastic rocker-only FEA used distributed bearing loads, a hinged pivot constraint and a small angular-reference fixture.

Baseline studies covered ride, bump, droop and reverse loading; optimized studies covered bump and reverse. Bump meshes were refined from **1.5/0.3 mm** to **1.2/0.24 mm** maximum/minimum sizes.

## Key results

| Metric | Baseline | Optimized |
|---|---:|---:|
| Rocker mass | 613.86 g | 572.63 g |
| Bump stress, matched mesh | 82.43 MPa | 83.80 MPa |
| Bump displacement, matched mesh | 0.04651 mm | 0.06127 mm |
| Bump stress, fine mesh | 85.14 MPa | 83.87 MPa |
| Reverse stress, matched mesh | 31.60 MPa | 31.30 MPa |

**Load cases:** bump at +30 mm with an assumed 6 kN vertical input; reverse at ride with a 2 kN reversed input. Stress is maximum nodal von Mises; displacement is maximum resultant URES. Matched mesh is 1.5/0.3 mm; fine mesh is 1.2/0.24 mm.

At ride, the measured local motion ratio is approximately **0.80**. The full sweep requires **21.19 mm damper compression** and **27.33 mm extension**, with the ratio decreasing toward bump. Final bump refinement changed stress by **3.29%** for the baseline and **0.084%** for the optimized body; displacement changed by less than **0.1%** in both.

The author confirmed smooth assembly movement and no remaining interferences at ride, bump and droop after eight known thread-envelope overlaps were ignored. These were discrete-position checks, not continuous collision verification.

## Interpretation and scope

The **41.23 g mass saving** increases compliance: matched-mesh bump displacement rises **31.74%**, while stress rises **1.66%**. The small fine-mesh stress difference is insufficient to claim improved strength.

Guided input travel is a wheel-motion surrogate, not a complete suspension model, and the ratio departs from the initial constant-ratio target. The work includes nominal part/assembly drawings and a BOM. Fatigue, hardware and chassis strength, manufacturing fits/tolerances and physical testing remain outside this concept study.

## Supporting project material

- [Optimized assembly image](../Images/evidence/optimized_assembly.png)
- [Mass comparison](../Plots/mass_comparison.png)
- [Matched-mesh stress and displacement comparison](../Plots/matched_mesh_comparison.png)
- [Motion-ratio curve](../Plots/motion_ratio.png)
- [Mesh-refinement comparison](../Plots/mesh_convergence.png)
- [Rocker drawing](../Drawings/Rocker_Optimized.pdf) and [assembly drawing](../Drawings/Rocker_Assembly_Optimized.pdf)
- [Full engineering documentation](../README.md#read-the-engineering-work)

*Portfolio concept based on CAD measurements and idealized static analysis. Not a manufacturing release.*

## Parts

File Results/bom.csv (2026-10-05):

item | part_number | quantity
1 | Pivot_Bracket | 1
2 | Pivot_Shaft | 1
3 | Rocker_Optimized | 1
4 | Pivot_Bearing_Envelope | 2
5 | Pivot_Centre_Spacer | 1
6 | Pivot_Outer_Spacer | 2
7 | Pivot_Bearing_Retainer | 2
8 | Pivot_Shaft_End_Retainer | 2
9 | M6_Flat_Washer_Baseline | 2
10 | M6x16_Screw_Envelope | 2
11 | M4_Flat_Washer_Baseline | 6
12 | M4x8_Screw_Envelope | 6
13 | Link_Clevis_Baseline | 4
14 | Pushrod_Tube_Baseline | 1
15 | Damper_Body_Envelope | 1
16 | Damper_Rod_Envelope | 1
17 | Mounting_Lug_Envelope | 2
18 | Link_Pin_Baseline | 4
19 | Link_Pin_Washer | 4
20 | Split_Pin_Installed_Envelope | 4

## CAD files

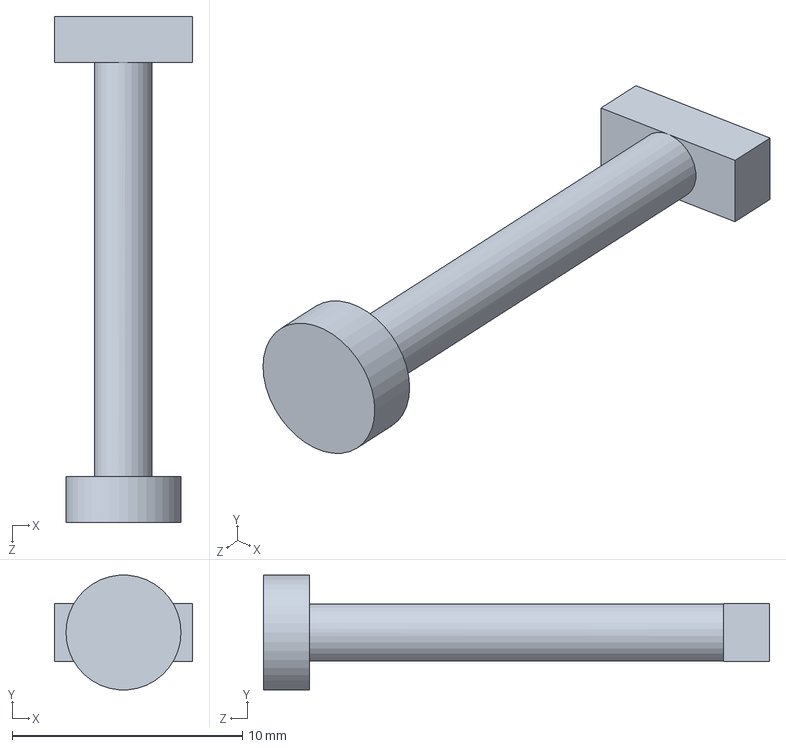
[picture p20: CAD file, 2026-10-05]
CAD/Split_Pin_Installed_Envelope.SLDPRT
6.00 x 4.98 x 22.0 mm

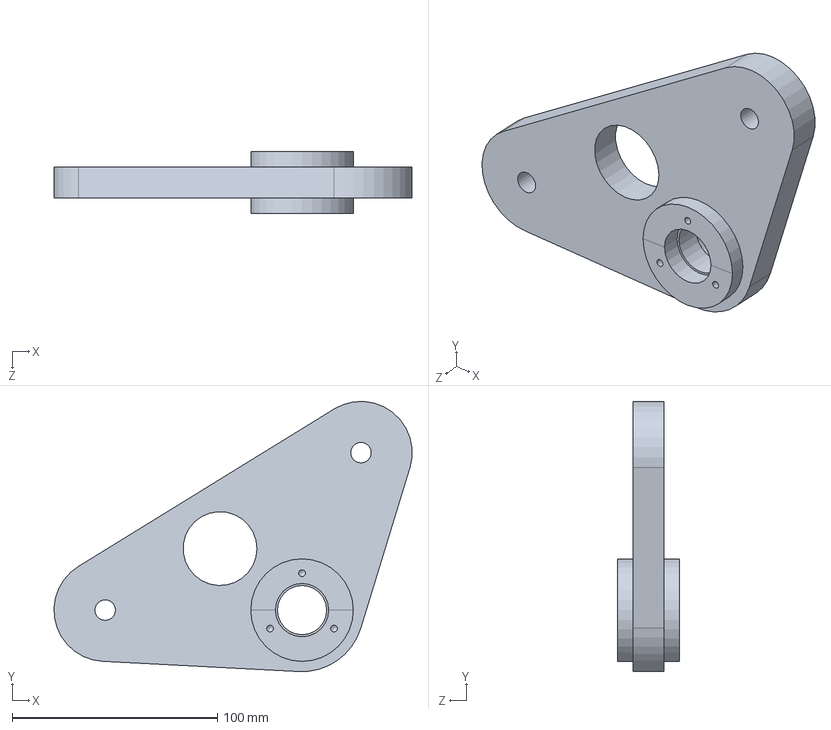
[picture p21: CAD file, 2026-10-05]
CAD/Rocker_Optimized.SLDPRT
174.6 x 131.7 x 30.0 mm

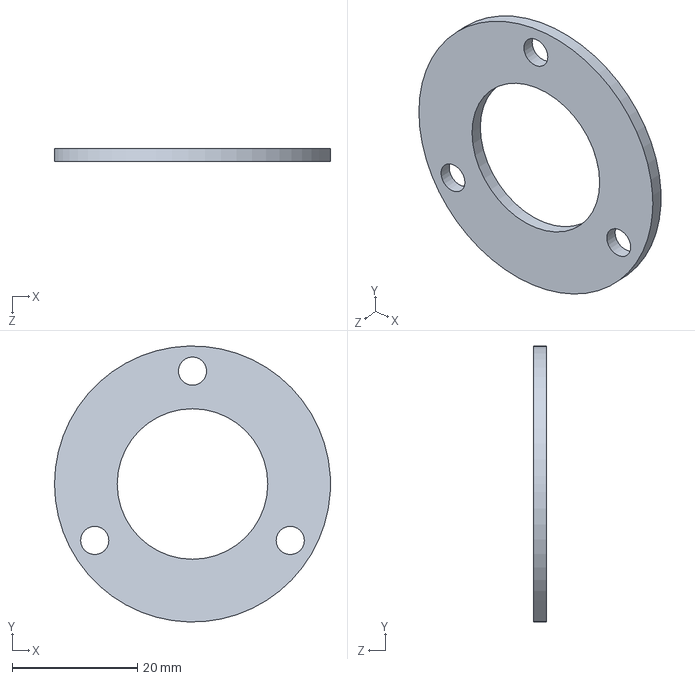
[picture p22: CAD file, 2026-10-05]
CAD/Pivot_Bearing_Retainer.SLDPRT
44.0 x 44.0 x 2.00 mm

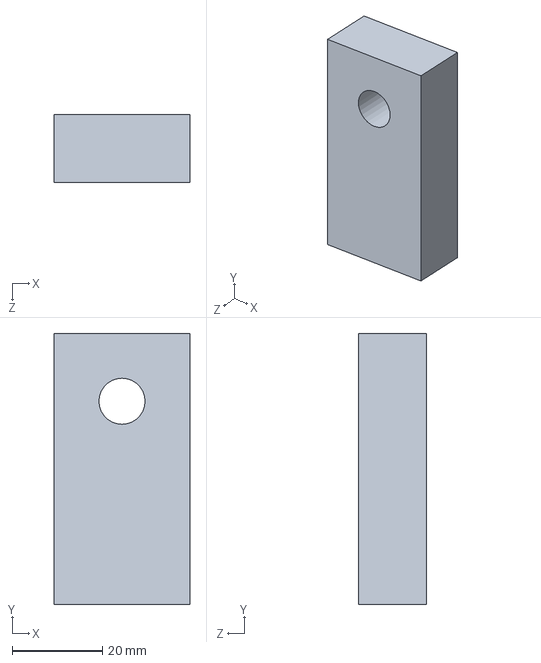
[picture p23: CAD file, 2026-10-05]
CAD/Mounting_Lug_Envelope.SLDPRT
30.0 x 60.0 x 15.0 mm

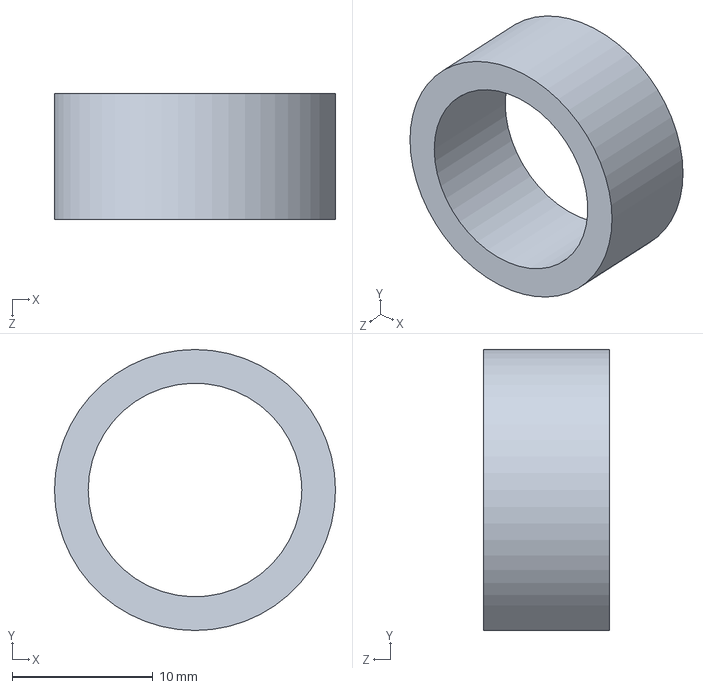
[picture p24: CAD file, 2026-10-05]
CAD/Pivot_Centre_Spacer.SLDPRT
20.0 x 20.0 x 9.00 mm

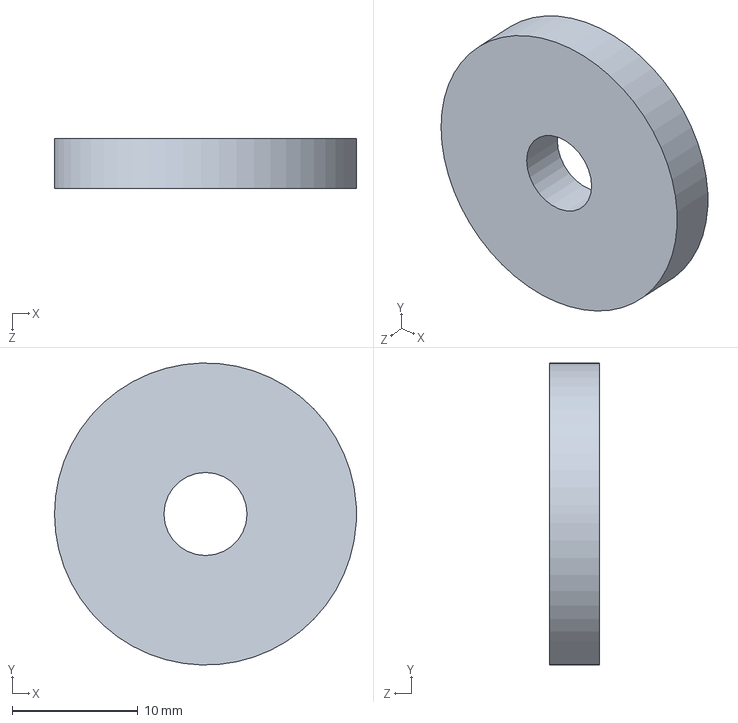
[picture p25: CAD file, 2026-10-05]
CAD/Pivot_Shaft_End_Retainer.SLDPRT
24.0 x 24.0 x 4.00 mm

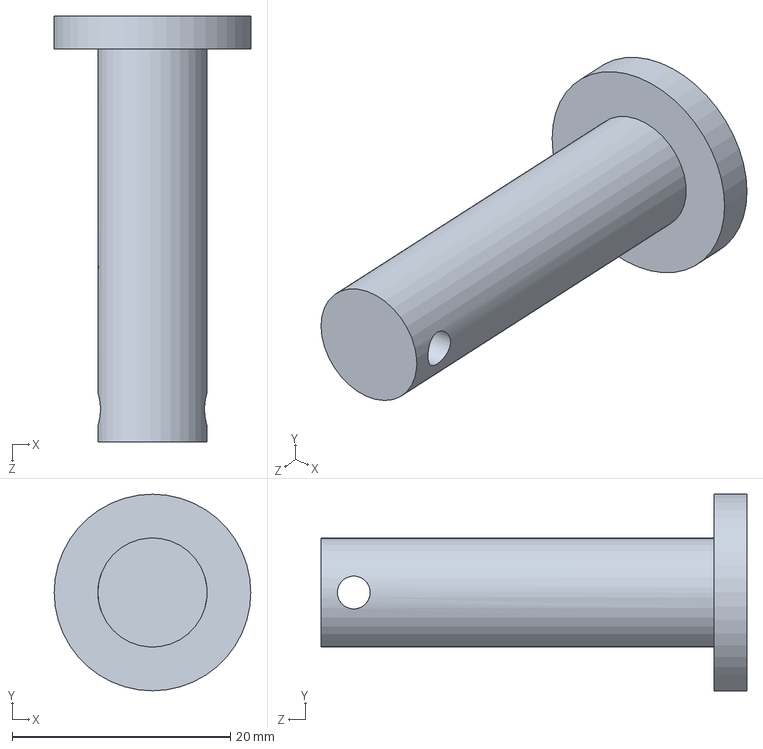
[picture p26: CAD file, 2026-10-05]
CAD/Link_Pin_Baseline.SLDPRT
18.0 x 18.0 x 39.0 mm

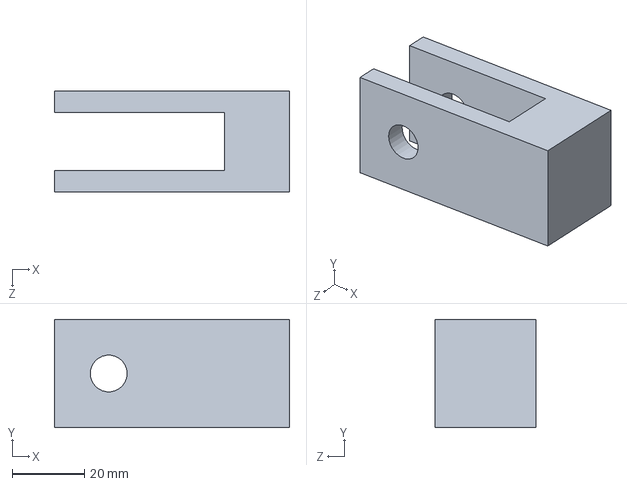
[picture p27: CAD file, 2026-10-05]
CAD/Link_Clevis_Baseline.SLDPRT
65.0 x 30.0 x 28.0 mm

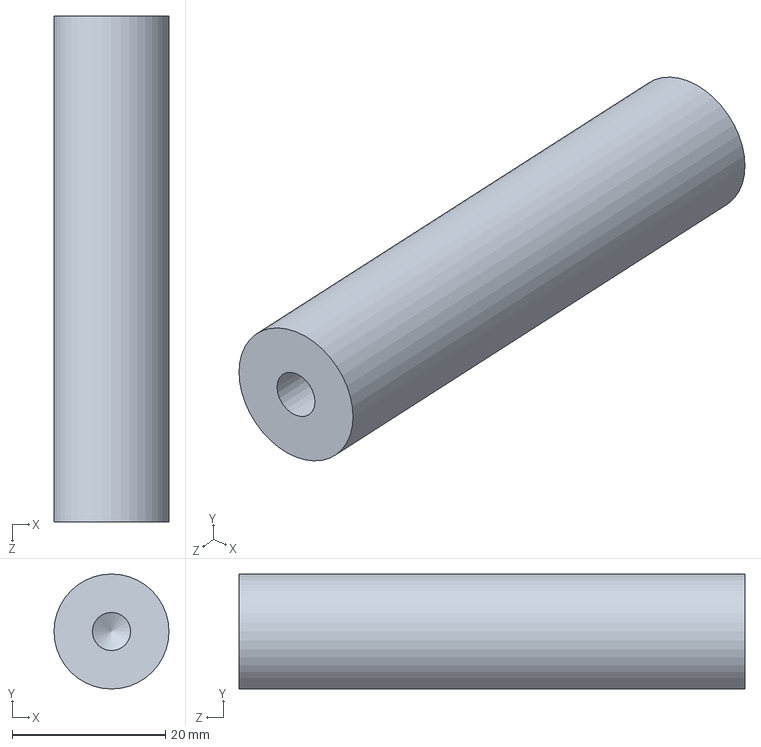
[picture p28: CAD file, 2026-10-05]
CAD/Pivot_Shaft.SLDPRT
15.0 x 15.0 x 66.0 mm

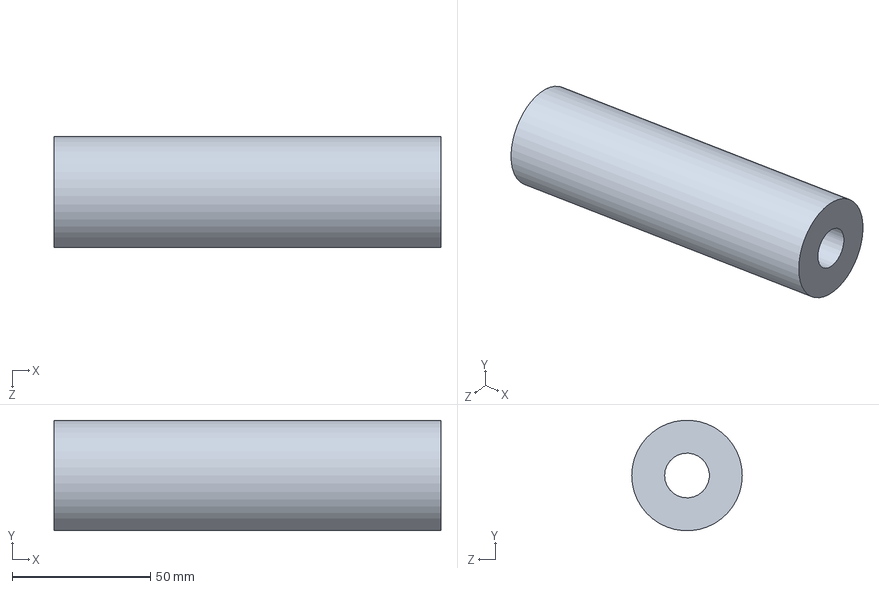
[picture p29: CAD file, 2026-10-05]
CAD/Damper_Body_Envelope.SLDPRT
140.0 x 39.9 x 40.0 mm

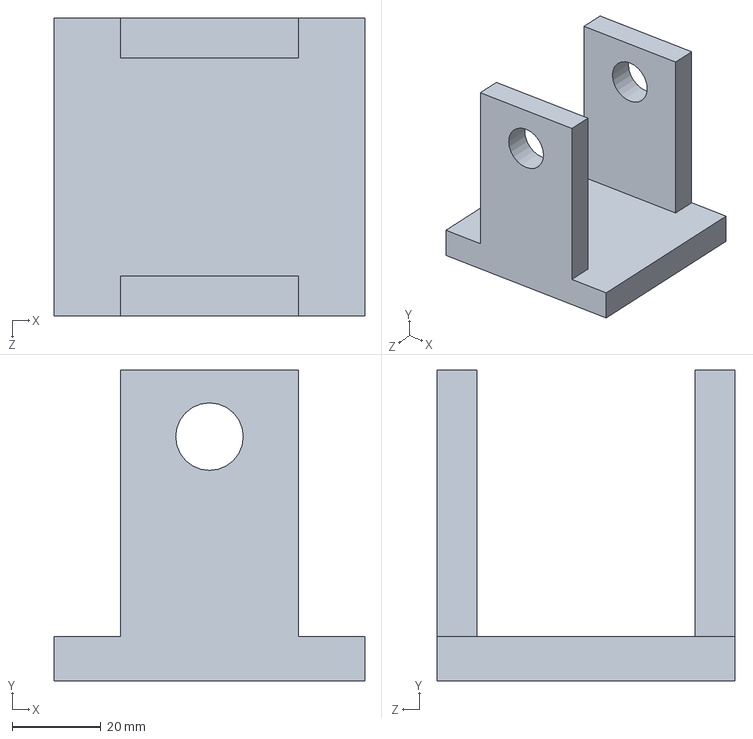
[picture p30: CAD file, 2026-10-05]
CAD/Pivot_Bracket.SLDPRT
70.0 x 70.0 x 67.0 mm

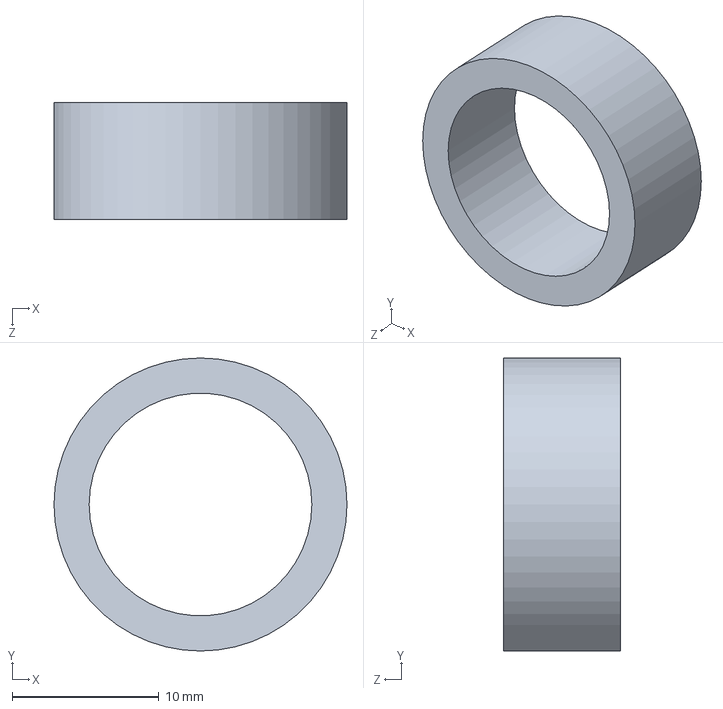
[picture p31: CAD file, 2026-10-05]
CAD/Pivot_Outer_Spacer.SLDPRT
20.0 x 20.0 x 8.00 mm

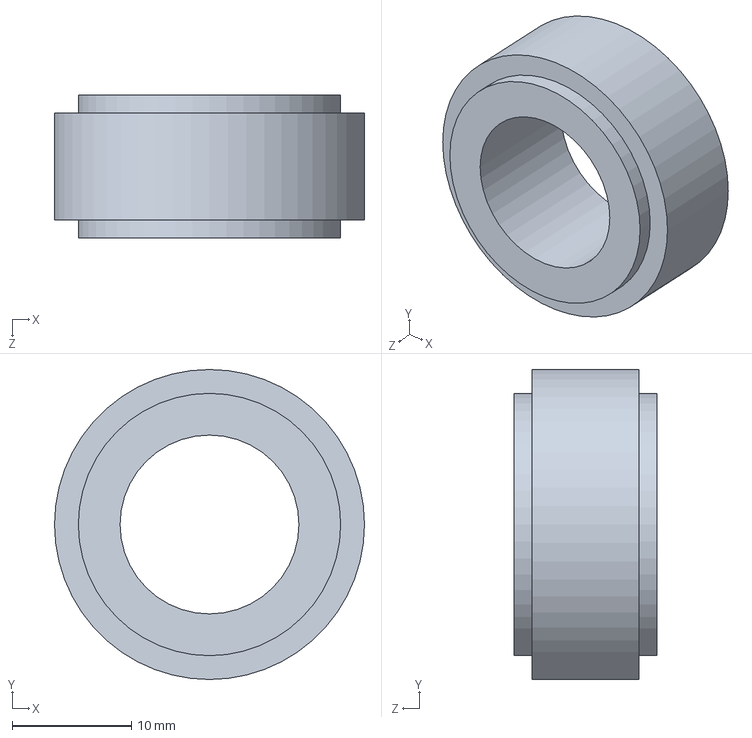
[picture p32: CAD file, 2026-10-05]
CAD/Pivot_Bearing_Envelope.SLDPRT
26.0 x 26.0 x 12.0 mm

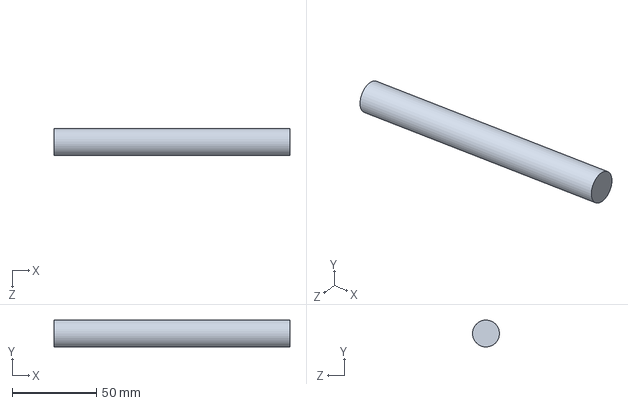
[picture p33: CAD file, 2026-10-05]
CAD/Damper_Rod_Envelope.SLDPRT
140.0 x 16.0 x 16.0 mm

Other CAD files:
CAD/Rocker_Assembly_Optimized.SLDASM
CAD/Rocker_Assembly_Baseline.SLDASM
CAD/Rocker_Baseline.SLDPRT
CAD/Pushrod_Tube_Baseline.SLDPRT
CAD/Link_Pin_Washer.SLDPRT
CAD/M4_Flat_Washer_Baseline.SLDPRT
CAD/M4x8_Screw_Envelope.SLDPRT
CAD/M6_Flat_Washer_Baseline.SLDPRT
CAD/M6x16_Screw_Envelope.SLDPRT
CAD/Rocker_Layout.SLDPRT
Drawings/Rocker_Assembly_Optimized.SLDDRW
Drawings/Rocker_Optimized.SLDDRW

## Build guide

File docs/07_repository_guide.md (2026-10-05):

# Repository layout and native-file handoff

## Use the current repository

1. Use `D:\Suspension_Rocker_Solidworks\suspension-rocker-solidworks` as the main local repository.
2. Review `README.md` and preserve the folder layout and relative links.
3. Before publishing, review `git status` and the ignored-file policy. Locally present files are not necessarily committed or available in a remote clone.
4. Keep `README.md` at the repository root when publishing to GitHub.
5. Review the rendered README to check that its images and PDF links work.

Suggested repository description: **Conceptual suspension rocker design in SolidWorks: kinematics, assembly verification, static FEA, mesh convergence and mass reduction.**

Suggested topics: `solidworks`, `fea`, `suspension`, `motorsport`, `mechanical-design`, `cad`, `engineering-portfolio`.

## Native files now present

Copies of the native files from the source SolidWorks project are now organized in the local repository. The source project was left unchanged. The existing CSV records remain transcribed summaries. Reference and result-path resolution in SolidWorks was not checked as part of this documentation review.

- `CAD/` contains 22 `.SLDPRT` models and both `.SLDASM` assemblies. Verify that both assemblies open from this location without missing-reference prompts and use the repository copies of their components. Use Pack and Go if further reference gathering is needed; preserve filenames.
- `Drawings/` contains both native `.SLDDRW` sources and both PDFs. Verify that the native drawings resolve their model references to `CAD/`.
- `Simulation/` contains copied solver results and supporting artifacts. `.CWR` and `.LOG` files are excluded by `.gitignore`; archive them separately if they are needed for a published handoff. Verify the studies' result paths against this folder before using the copied results.
- `Animations/` contains `Rocker_Travel_Baseline.avi`. No optimized travel video is included.
- `Results/` contains the existing CSV summaries, evidence manifest and two copied interference-calculation `.xlsx` spreadsheets.
- The baseline AVI is tracked with Git LFS through `.gitattributes`. Install Git LFS and run `git lfs pull` after cloning to retrieve the video content. CAD and drawing files are tracked as regular Git binaries; solver caches retain the existing ignore policy.

## Publication checks

Before uploading native files, inspect Pack and Go content for unrelated projects, private paths or identifying metadata. Select a license intentionally; the package does not grant an open-source license by default. Keep the stated concept scope and known limitations visible in the README.

The repository can present the completed engineering work now. Native SolidWorks reproducibility still depends on verifying the copied model references and study result paths, and making any required Git-ignored results available with the handoff. A reader can already regenerate all included summary charts from the CSV files.

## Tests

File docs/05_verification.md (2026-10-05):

# Assembly verification and drawings

## Mechanism and hardware

The pivot assembly includes a fixed bracket, Ø15 mm shaft, two bearing envelopes, centre/outer spacers, bearing retainers and end retainers. Four clevis joints connect the pushrod, rocker, damper and mounting lugs. Pins pass through double-shear ears; washers and installed split-pin envelopes illustrate retention.

These are geometric envelopes rather than certified catalogue components. In particular the damper is a telescoping body/rod envelope, without a physical spring, piston or catalogue stroke rating. The bearing proxy does not establish its load rating, fits or oscillatory life. The bracket and remote lugs do not include validated chassis attachment details.

## Motion and interference evidence

| Optimized position | Guided input | Known overlaps ignored | Remaining interferences |
|---|---:|---:|---:|
| Nominal ride | 0 mm | 8 | 0 |
| Bump | +30 mm | 8 | 0 |
| Droop | -30 mm | 8 | 0 |

The author confirmed smooth complete optimized movement. The eight ignored intersections are two M6 and six M4 simplified screw/thread envelope overlaps. Treat coincidence as interference was off, hidden components were not excluded and no other components were excluded. These are discrete-position interference checks; smooth dragging is not a continuous collision-detection proof or a tolerance-clearance check.

The baseline mechanism was also checked at ride and ±10/±20/±30 mm input positions. Mate Controller positions and the baseline animation were exercised; the author confirmed that the saved video played correctly. The video is now included as [Rocker_Travel_Baseline.avi](../Animations/Rocker_Travel_Baseline.avi); playback of the repository copy was not checked as part of this documentation review. No physical assembly has been tested.

## Drawings

- [Rocker part](../Drawings/Rocker_Optimized.pdf): A3, scale 1:1, nominal profile/hole dimensions, plate/hub thickness, threaded retainer pattern, material and body mass.
- [Assembly](../Drawings/Rocker_Assembly_Optimized.pdf): A3, overall scale 1:4, section A-A, detail E at 1:2, 20-item BOM and balloons.

The part drawing uses R13 for the Ø26 seat and includes its axial depths. The assembly material field references individual parts, and assembly weight is intentionally blank because rocker body mass is not total assembly mass.

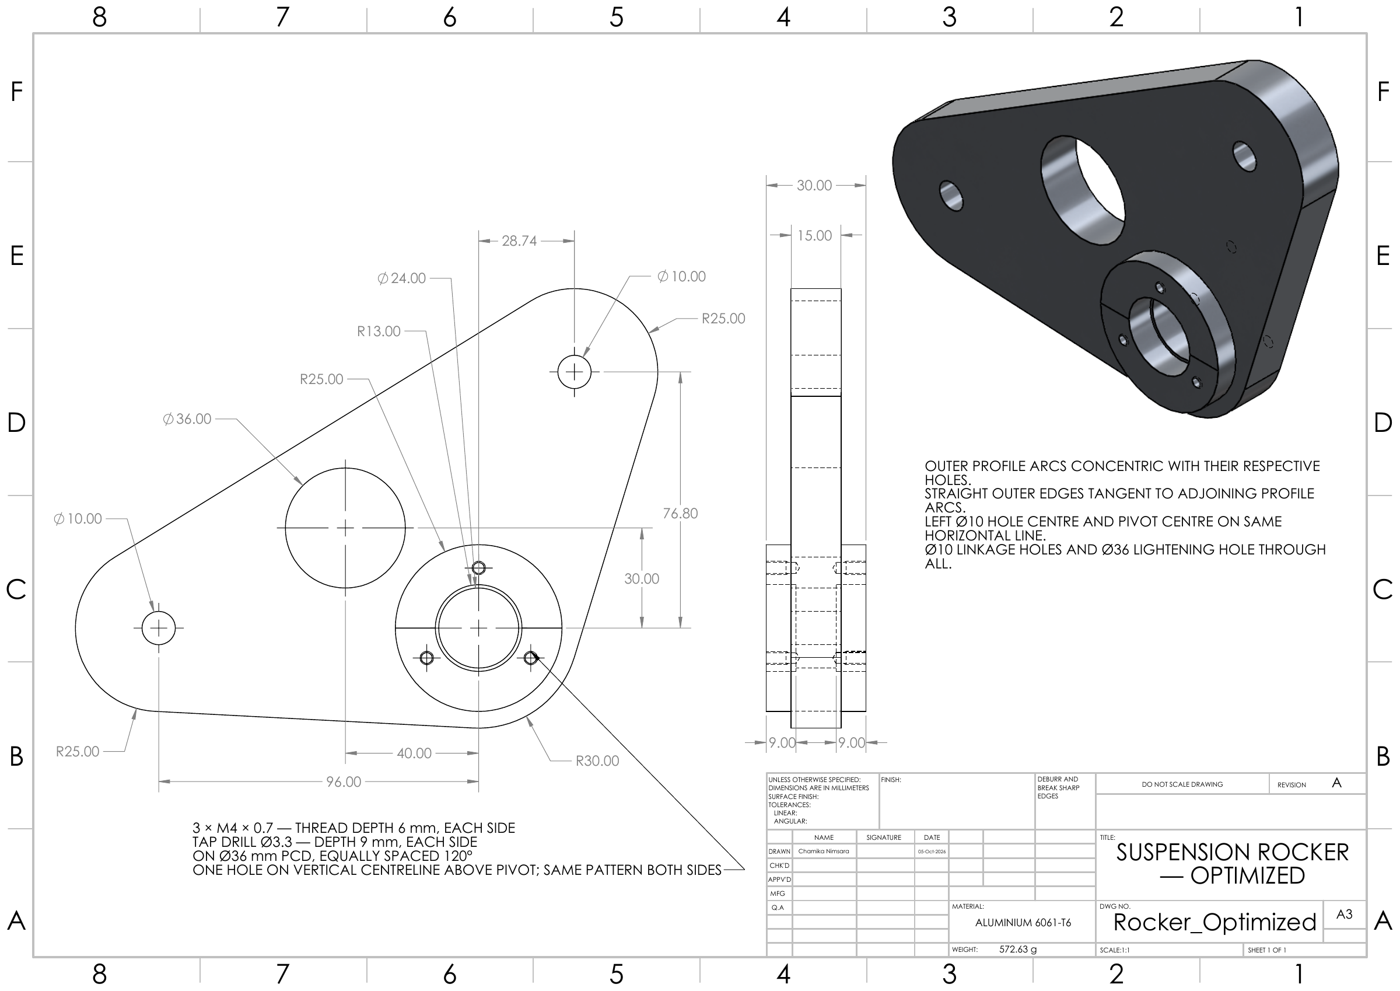
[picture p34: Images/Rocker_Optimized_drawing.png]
Part drawing

Assembly drawing

The PDFs were visually reviewed for clipping and readable layout. Grey reference markers in assembly detail E were retained at the author's request. General tolerances, bearing fits, datums/GD&T, certified material and complete component drawings are not established, so these are concept drawings rather than released manufacturing instructions.

## Completed and open work

Completed: CAD bodies, baseline/optimized assemblies, guided travel study, selected rocker static FEA, final bump mesh-refinement checks, nominal drawings and PDF export.

Open for a real vehicle: actual hard-point confirmation, steering and full suspension sweep, duty-cycle loads, spring/damper selection, minimum clearance, hardware/chassis assessment, fatigue, proof testing and manufacturing release.

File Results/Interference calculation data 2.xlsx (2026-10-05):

Interference ID | Interference volume (mm^3) | Component 1 name | Component 2 name | Component 1 full reference | Component 2 full reference
Interference1 | 85.53 | Pivot_Shaft-1 | M6x16_Screw_Envelope-2 | Pivot_Shaft-1 | M6x16_Screw_Envelope-2
Interference2 | 85.53 | Pivot_Shaft-1 | M6x16_Screw_Envelope-1 | Pivot_Shaft-1 | M6x16_Screw_Envelope-1
Interference3 | 20.07 | Rocker_Baseline-1 | M4x8_Screw_Envelope-2 | Rocker_Baseline-1 | M4x8_Screw_Envelope-2
Interference4 | 20.07 | Rocker_Baseline-1 | M4x8_Screw_Envelope-3 | Rocker_Baseline-1 | M4x8_Screw_Envelope-3
Interference5 | 20.07 | Rocker_Baseline-1 | M4x8_Screw_Envelope-4 | Rocker_Baseline-1 | M4x8_Screw_Envelope-4
Interference6 | 20.07 | Rocker_Baseline-1 | M4x8_Screw_Envelope-5 | Rocker_Baseline-1 | M4x8_Screw_Envelope-5
Interference7 | 20.07 | Rocker_Baseline-1 | M4x8_Screw_Envelope-1 | Rocker_Baseline-1 | M4x8_Screw_Envelope-1
Interference8 | 20.07 | Rocker_Baseline-1 | M4x8_Screw_Envelope-6 | Rocker_Baseline-1 | M4x8_Screw_Envelope-6

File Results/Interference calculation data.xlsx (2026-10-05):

Interference ID | Interference volume (mm^3) | Component 1 name | Component 2 name | Component 1 full reference | Component 2 full reference
Interference1 | 85.53 | Pivot_Shaft-1 | M6x16_Screw_Envelope-2 | Pivot_Shaft-1 | M6x16_Screw_Envelope-2
Interference2 | 85.53 | Pivot_Shaft-1 | M6x16_Screw_Envelope-1 | Pivot_Shaft-1 | M6x16_Screw_Envelope-1
Interference3 | 20.07 | Rocker_Baseline-1 | M4x8_Screw_Envelope-6 | Rocker_Baseline-1 | M4x8_Screw_Envelope-6
Interference4 | 20.07 | Rocker_Baseline-1 | M4x8_Screw_Envelope-1 | Rocker_Baseline-1 | M4x8_Screw_Envelope-1
Interference5 | 20.07 | Rocker_Baseline-1 | M4x8_Screw_Envelope-2 | Rocker_Baseline-1 | M4x8_Screw_Envelope-2
Interference6 | 20.07 | Rocker_Baseline-1 | M4x8_Screw_Envelope-3 | Rocker_Baseline-1 | M4x8_Screw_Envelope-3
Interference7 | 20.07 | Rocker_Baseline-1 | M4x8_Screw_Envelope-5 | Rocker_Baseline-1 | M4x8_Screw_Envelope-5
Interference8 | 20.07 | Rocker_Baseline-1 | M4x8_Screw_Envelope-4 | Rocker_Baseline-1 | M4x8_Screw_Envelope-4
Interference9 | 1 | Link_Pin_Washer-3 | Split_Pin_Installed_Envelope-1 | Link_Pin_Washer-3 | Split_Pin_Installed_Envelope-1
Interference10 | 1 | Link_Pin_Washer-1 | Split_Pin_Installed_Envelope-3 | Link_Pin_Washer-1 | Split_Pin_Installed_Envelope-3
Interference11 | 1 | Link_Pin_Washer-2 | Split_Pin_Installed_Envelope-4 | Link_Pin_Washer-2 | Split_Pin_Installed_Envelope-4
Interference12 | 1 | Link_Pin_Washer-4 | Split_Pin_Installed_Envelope-2 | Link_Pin_Washer-4 | Split_Pin_Installed_Envelope-2

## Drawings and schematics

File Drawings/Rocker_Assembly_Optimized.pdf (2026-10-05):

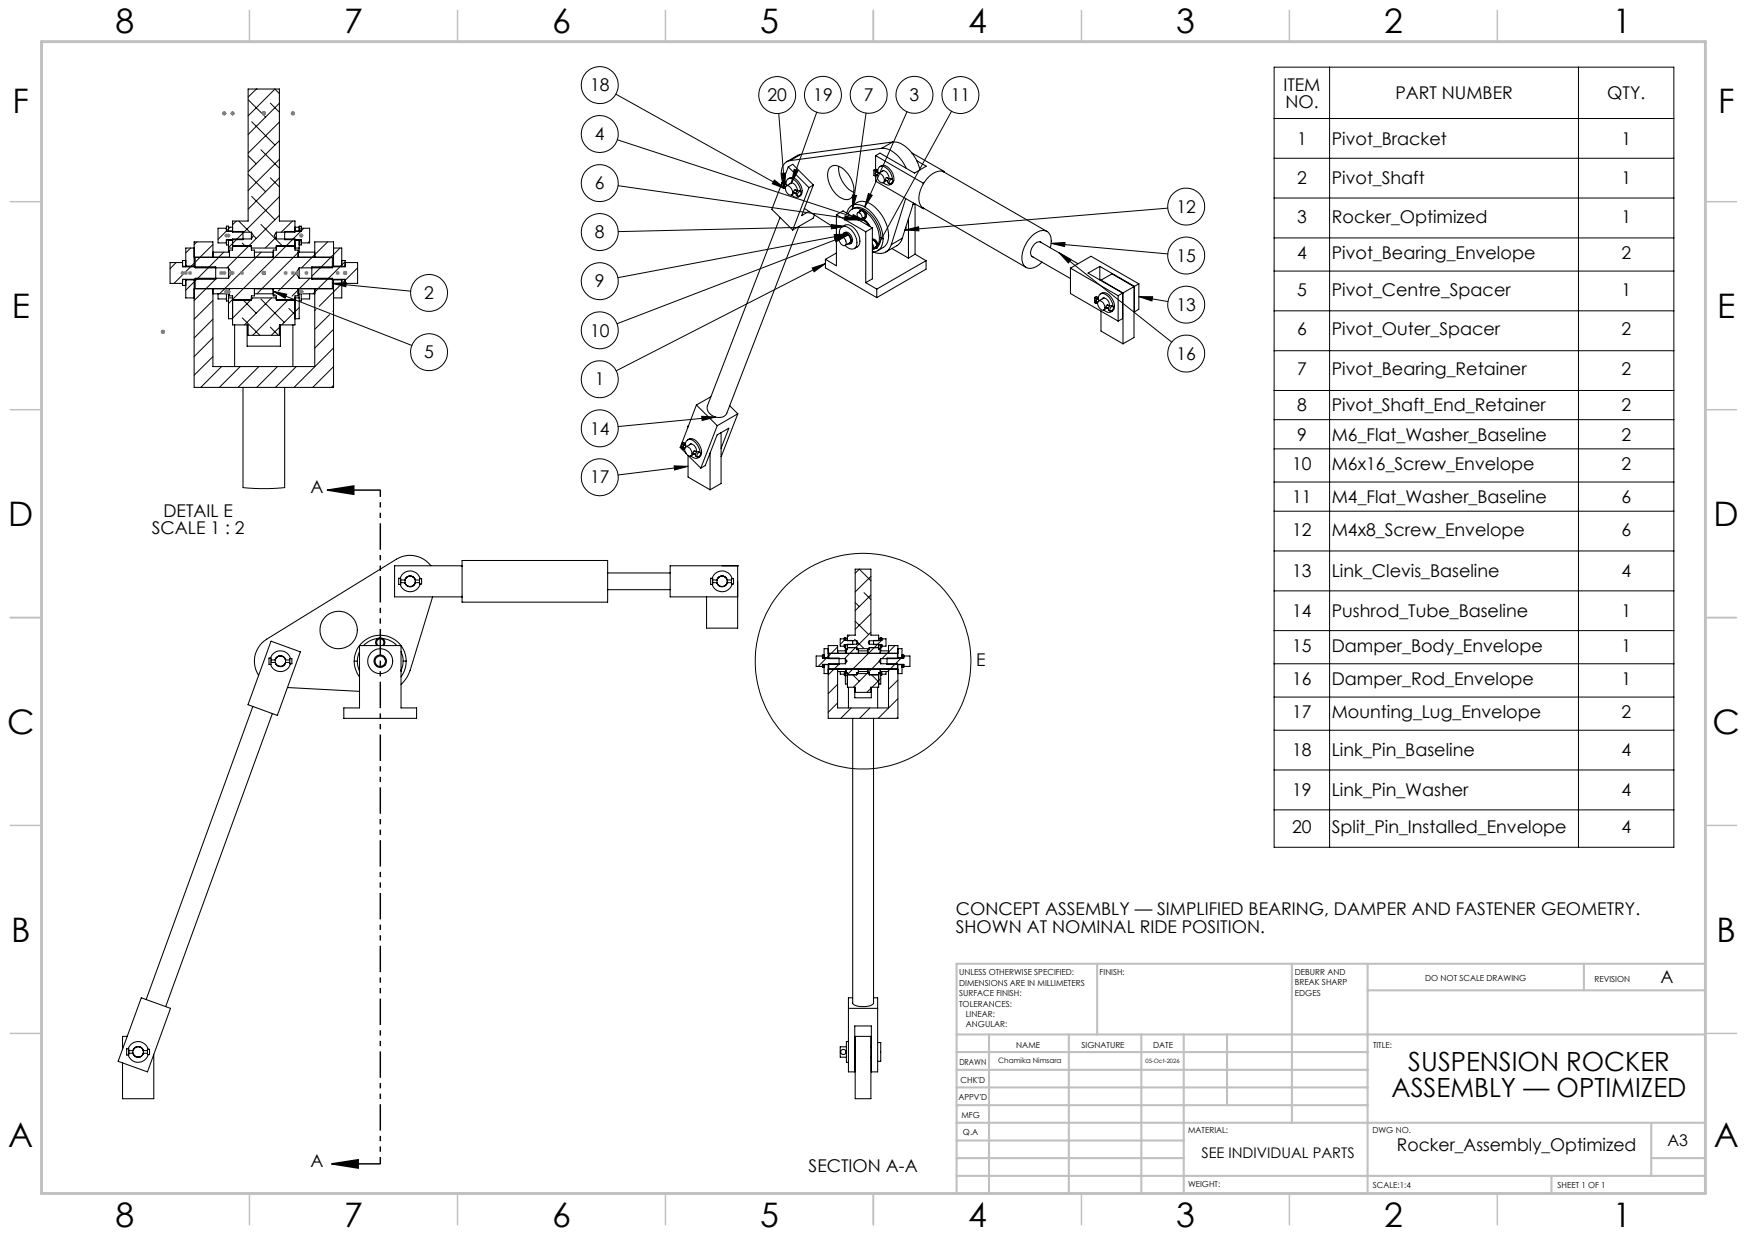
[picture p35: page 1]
SECTION A-A; DETAIL E SCALE 1 : 2; FINISH:; DEBURR AND; BREAK SHARP; DO NOT SCALE DRAWING; REVISION; SCALE:1:4; SHEET 1 OF 1

ITEM NO. | PART NUMBER | QTY.

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

CONCEPT ASSEMBLY — SIMPLIFIED BEARING, DAMPER AND FASTENER GEOMETRY.
SHOWN AT NOMINAL RIDE POSITION.

UNLESS OTHERWISE SPECIFIED:
DIMENSIONS ARE IN MILLIMETERS
SURFACE FINISH:
TOLERANCES:
LINEAR:
ANGULAR:

NAME | SIGNATURE | DATE | | | | TITLE: SUSPENSION ROCKER ASSEMBLY — OPTIMIZED

DRAWN | Chamika Nimsara | | 05-Oct-2026
CHK'D
APPV'D
MFG
Q.A | | | | MATERIAL: SEE INDIVIDUAL PARTS | DWG NO. Rocker_Assembly_Optimized | A3

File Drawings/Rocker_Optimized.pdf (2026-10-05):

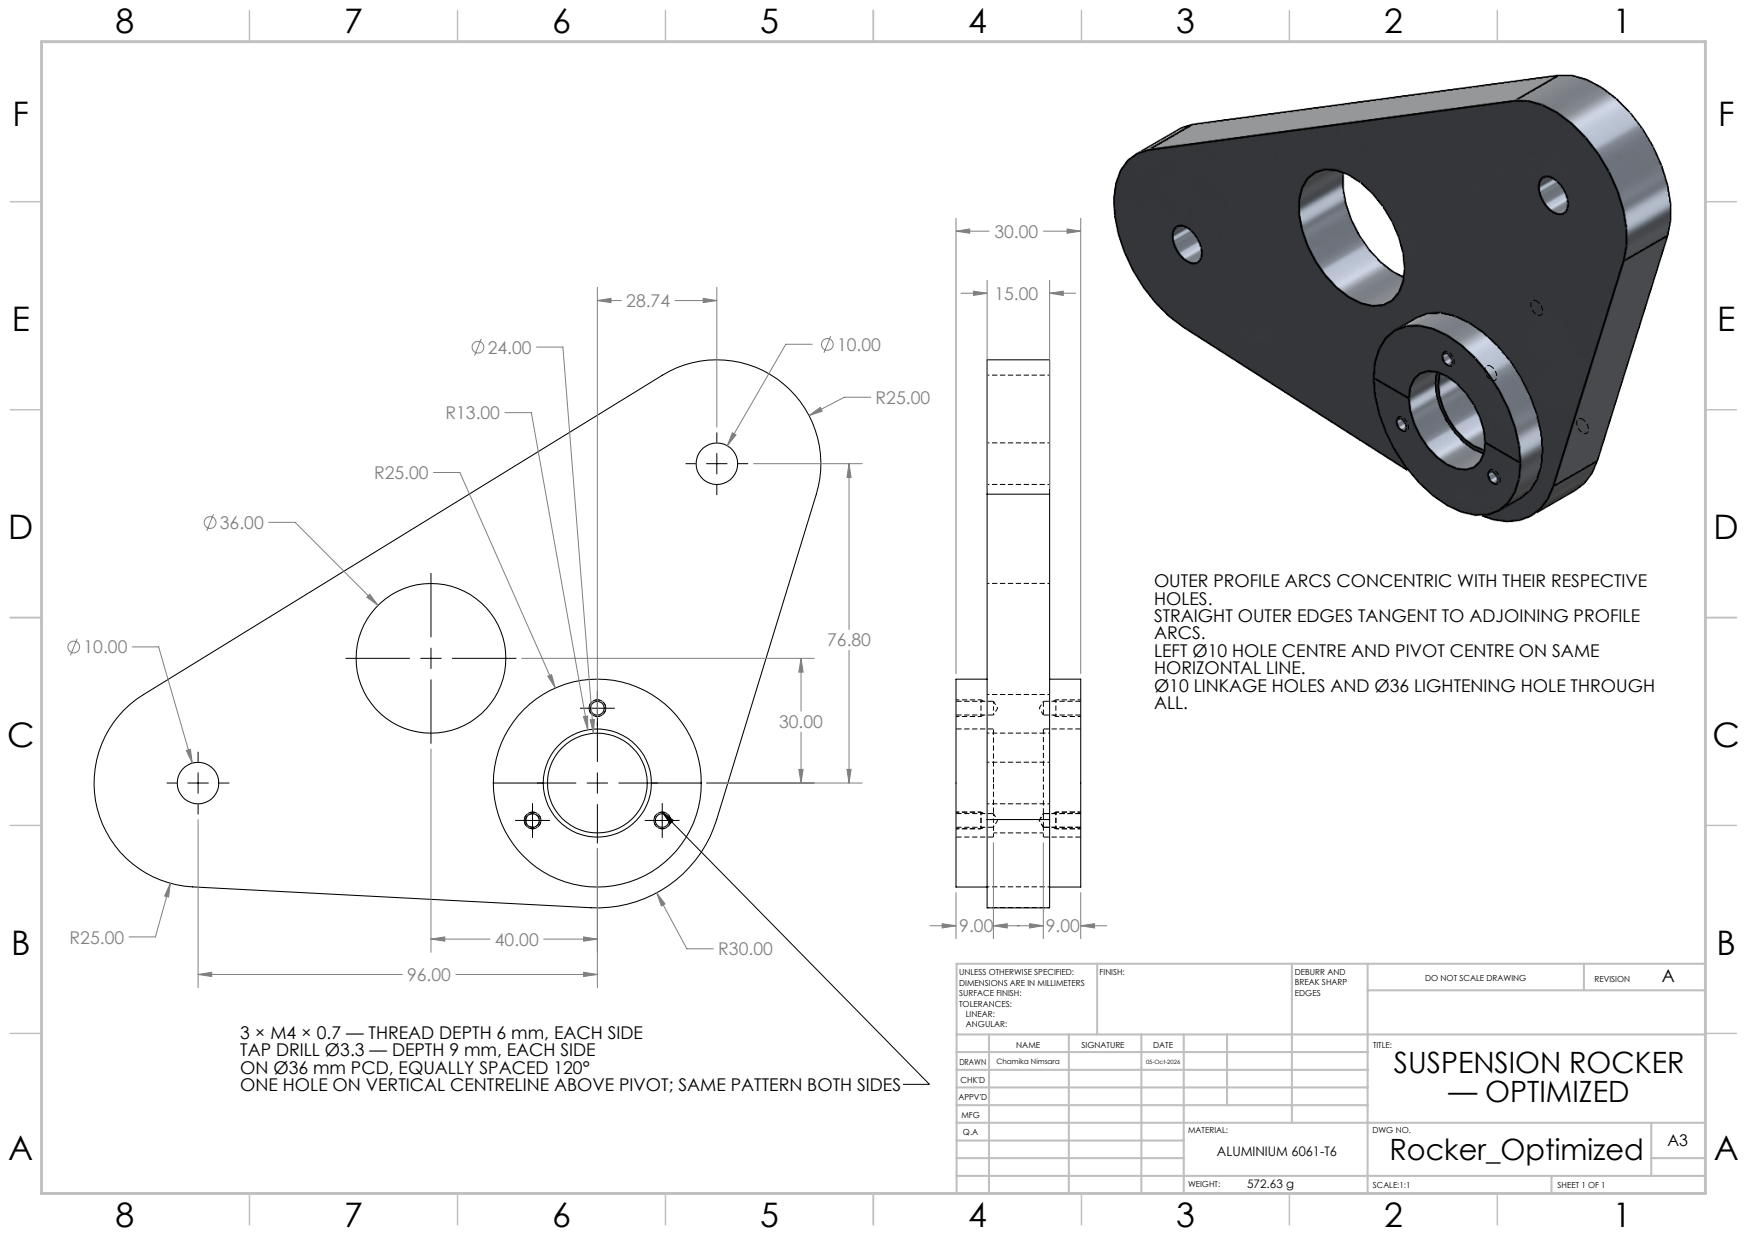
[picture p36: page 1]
FINISH:; DEBURR AND; BREAK SHARP; DO NOT SCALE DRAWING; REVISION; SCALE:1:1; SHEET 1 OF 1

OUTER PROFILE ARCS CONCENTRIC WITH THEIR RESPECTIVE
HOLES.
STRAIGHT OUTER EDGES TANGENT TO ADJOINING PROFILE
ARCS.
LEFT Ø10 HOLE CENTRE AND PIVOT CENTRE ON SAME
HORIZONTAL LINE.
Ø10 LINKAGE HOLES AND Ø36 LIGHTENING HOLE THROUGH
ALL.

UNLESS OTHERWISE SPECIFIED:
DIMENSIONS ARE IN MILLIMETERS
SURFACE FINISH:
TOLERANCES:
LINEAR:
ANGULAR:

3 × M4 × 0.7 — THREAD DEPTH 6 mm, EACH SIDE
TAP DRILL Ø3.3 — DEPTH 9 mm, EACH SIDE
ON Ø36 mm PCD, EQUALLY SPACED 120°
ONE HOLE ON VERTICAL CENTRELINE ABOVE PIVOT; SAME PATTERN BOTH SIDES

NAME | SIGNATURE | DATE | | | | TITLE: SUSPENSION ROCKER — OPTIMIZED

DRAWN | Chamika Nimsara | | 05-Oct-2026
CHK'D
APPV'D
MFG
Q.A | | | | MATERIAL: | DWG NO. Rocker_Optimized | A3 ALUMINIUM 6061-T6

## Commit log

2026-10-05 docs: publish reviewed suspension rocker engineering portfolio
    Add design basis, kinematics, rocker FEA, optimization and verification documentation with recorded results, evidence and reproducible charts. Clarify body-fixed load directions, rigid pushrod motion and native-file availability.
    [Interference calculation data 2.xlsx, Interference calculation data.xlsx, assembly_checks.csv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]
2026-10-05 feat: add native SolidWorks models and drawing sources
    Include baseline and optimized assemblies, component parts, native drawings, PDF exports and simulation support artifacts. Keep solver caches, logs and SolidWorks lock files excluded by the repositor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
    [Damper_Body_Envelope.SLDPRT, Damper_Rod_Envelope.SLDPRT, Link_Clevis_Baseline.SLDPRT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]
2026-10-05 build: track baseline suspension animation with Git LFS
    Add the baseline travel AVI through Git LFS and document how to retrieve its content after cloning.
